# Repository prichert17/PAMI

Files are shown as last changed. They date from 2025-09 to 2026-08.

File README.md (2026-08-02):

# Projet PAMI (2025-2026) - Eurobot

Ce dépôt documente le projet PAMI (Petit Actionneur Motorisé Indépendant) sur lequel j'ai travaillé pendant un an, dans le cadre de la coupe Eurobot 2026. Il centralise l'ensemble de la conception matérielle (deux PCB, structure mécanique) et logicielle du robot. 

<p align="center">
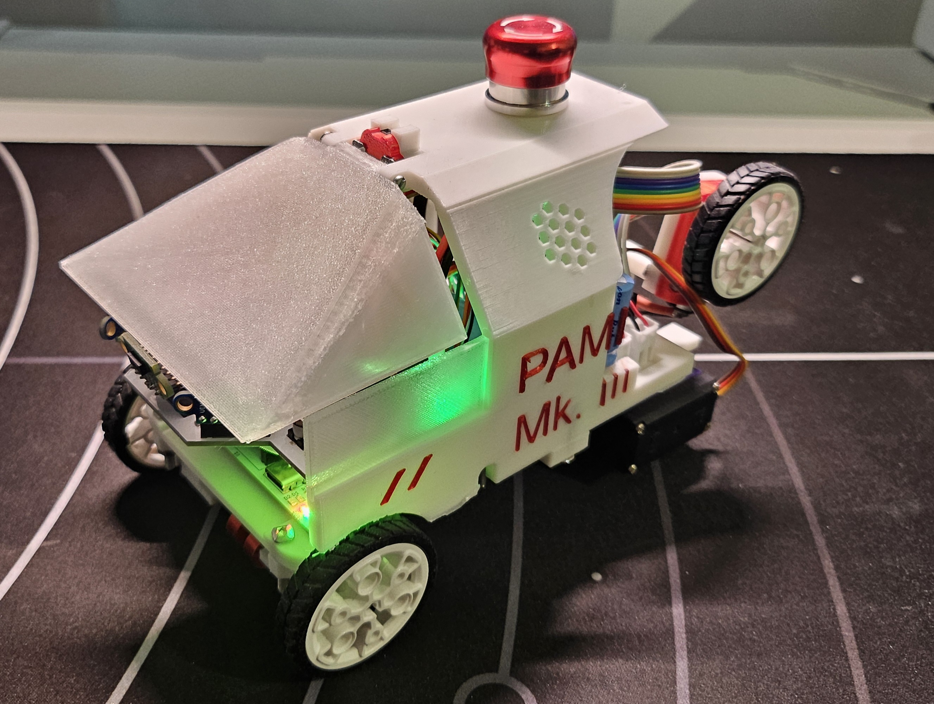
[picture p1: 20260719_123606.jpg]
  
  <br>
  <em>Légende : Photo du robot PAMI assemblé</em>
</p>

<p align="center">
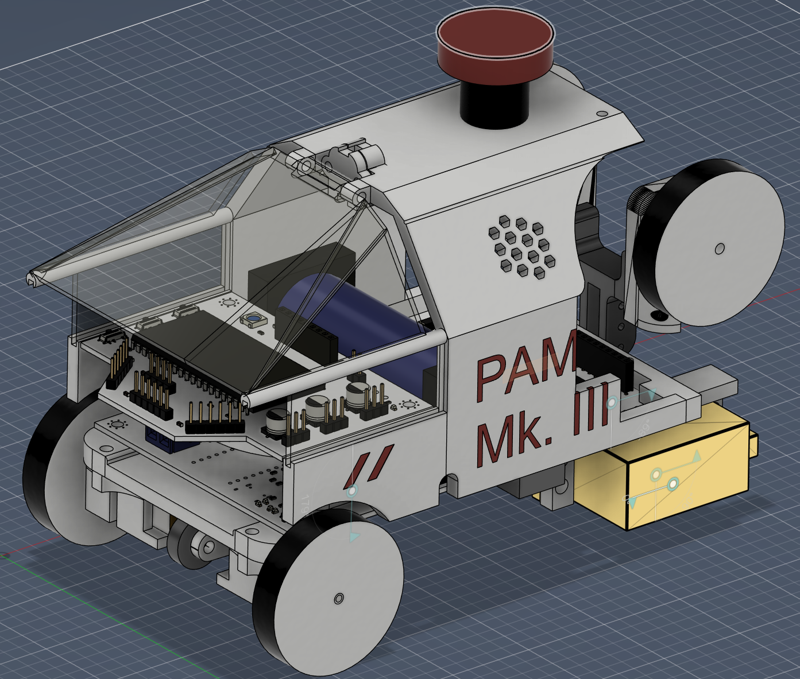
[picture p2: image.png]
  
  <br>
  <em>Légende : Rendu 3D du robot (Fusion 360)</em>
</p>

## Codes principaux

Pour mieux comprendre l'architecture du système, voici les trois éléments importants du dépôt :

*   **[`PAMI_2026/`](./Projects/PAMI_2026)** : Contient le code haut niveau qui est exécuté sur le microcontrôleur **ESP32**.
*   **[`Projects/Asservissement_G4/`](./Projects/Asservissement_G4)** : Contient tout le code de l'asservissement, de l'odométrie et le contrôle des moteurs. Ce code tourne sur la carte **NUCLEO-G431KB** (STM32).
*   **[`Projects/IHM_PAMI_2026.py`](./Projects/IHM_PAMI_2026.py)** : Une interface homme-machine (IHM) développée en Python qui permet de lire et visualiser en temps réel les coordonnées et l'état du PAMI lors des phases de tests.

---

## Architecture Bas Niveau : PCB Principal (Contrôle Moteurs & Alimentation)

Le robot dispose de deux cartes électroniques (PCB). La partie bas niveau, gérée par le PCB principal s'occupe de l'alimentation générale et de la motricité du robot. Le PAMI est assez compact : ses dimensions finales sont de 10.5cm par 19cm avec ses bras repliés (et 24cm bras dépliés), ce qui a imposé des contraintes sur le routage du circuit et le choix des composants.

### 1. Gestion de la Batterie et Alimentation
Le robot est alimenté par une unique cellule de batterie LiFePO4 au format 26650. Le circuit d'alimentation a subi plusieurs modifications suite à des problèmes rencontrés lors du développement :

*   **Le choix du LiFePO4 :** Bien que l'intégration de cette chimie ait rendu la conception du circuit d'alimentation plus complexe (notamment pour la régulation de tension, le prix plus élevé), c'est un choix qui reste très avantageux. Le LiFePO4 est extrêmement sécurisé (aucun risque d'incendie, pas besoin de sac ignifugé contrairement aux batteries LiPo), il offre un excellent courant de décharge (15A) pour les moteurs, et l'utilisation d'une seule et unique cellule simplifie grandement le processus de charge (pas d'équilibrage entre deux cellules nécessaire).
*   **Port USB C intégré :** Pour une simplicité d'usage maximale, un port USB C standard a été intégré au design, permettant de recharger facilement la batterie avec n'importe quel chargeur ou batterie externe.
*   **Circuit de Charge :** La charge est gérée directement sur le PCB par un composant dédié à ce type de batterie, le **CN3058E**, avec des LEDs indicatrices (Charge en cours / Charge terminée).
*   **Sécurité Batterie :** La batterie est surveillée par un IC de protection **HY2112**, associé à un double MOSFET N-Channel (FS8205A) pour couper le circuit en cas de problème.
*   **Régulation de tension :** La tension de la cellule LiFePO4 pouvant monter à 3.6V (ce qui est trop élevé pour l'ESP32 et certains capteurs), j'ai opté pour un convertisseur **Buck-Boost (TPS63000)** au lieu d'un simple circuit Boost. Il assure un 3.3V parfaitement stable en abaissant ou élevant la tension de la batterie selon les besoins, pour un courant jusqu'à 1A.
*   **Le problème des appels de courant :** Un problème est survenu avec l'alimentation des servomoteurs. Leurs appels de courant créaient d'énormes chutes de tension (la tension de la batterie chutait jusqu'à 2.4V pendant un court instant). Le robot ne parvenait pas à se lever de manière autonome, la tension de la batterie passait en dessous du seuil limite du circuit boost 6V. La cause : la résistance interne du boitier de la batterie 26650 et des pistes de cuivre trop fines (1.5mm) qui ne supportaient pas les pics d'intensité très élevés (pouvant monter jusqu'à 3A sur le rail 6V, soit quasiment 6A en sortie de la batterie). Le problème a été résolu en soudant un condensateur de 2200µF (10V) directement à l'entrée du boost 6V pour agir comme une réserve d'énergie, ce qui diminuait fortement la chute de tension.

### 2. Odométrie et Asservissement (NUCLEO-G431KB)
La carte intègre un microcontrôleur STM32 (NUCLEO-G431KB) programmé en C++ pour gérer la dynamique temps-réel du robot. Un travail conséquent a été réalisé sur la fiabilité des déplacements et la prévention du patinage.

*   **Odométrie Haute Fréquence (500Hz) :** La position exacte du robot (X, Y, Angle) est calculée 500 fois par seconde. Les encodeurs incrémentiels des roues renvoient des signaux en quadrature décodés de manière purement matérielle par les Timers du STM32. Le code gère les débordements de compteurs (overflow des timers 16 bits) pour assurer un suivi sans erreur.
*   **Asservissement PID en 2 Phases (100Hz) :** Le contrôle de la trajectoire s'effectue via une boucle PID (Proportionnel, Intégral, Dérivé) actualisée à 100Hz. Pour rejoindre une cible, l'algorithme utilise une logique en deux temps :
    1. **Rotation pure :** Le robot pivote sur lui-même pour s'aligner parfaitement vers sa cible.
    2. **Avance avec correction :** Une fois aligné, il avance en ligne droite tout en maintenant son angle de manière active. Si le robot doit dévier fortement, la commande linéaire est automatiquement réduite pour privilégier la rotation et garder un mouvement fluide.
*   **Traction Control & Anti-Patinage :** Les robots de la coupe Eurobot sont sujets au patinage (poussière, accélération forte), ce qui fausse instantanément l'odométrie. J'ai donc un algorithme de détection de glissement : si la différence de vitesse mesurée entre la roue gauche et droite devient anormalement élevée, le STM32 détecte la perte d'adhérence et réduit la commande PWM envoyée aux moteurs.
*   **Performances :** À pleine vitesse, les moteurs tournent à environ 5 tours/seconde, propulsant le PAMI à 68 cm/s (2.4 km/h). La dérive odométrique pure a été mesurée à environ 2cm d'erreur pour 1 mètre parcouru en ligne droite.
*   **Communication Inter-Cartes :** Le STM32 transmet continuellement ses données d'odométrie et son état au cerveau central (l'ESP32) via une liaison série (UART), dont le protocole est détaillé dans `pami_com.h`.

<p align="center">
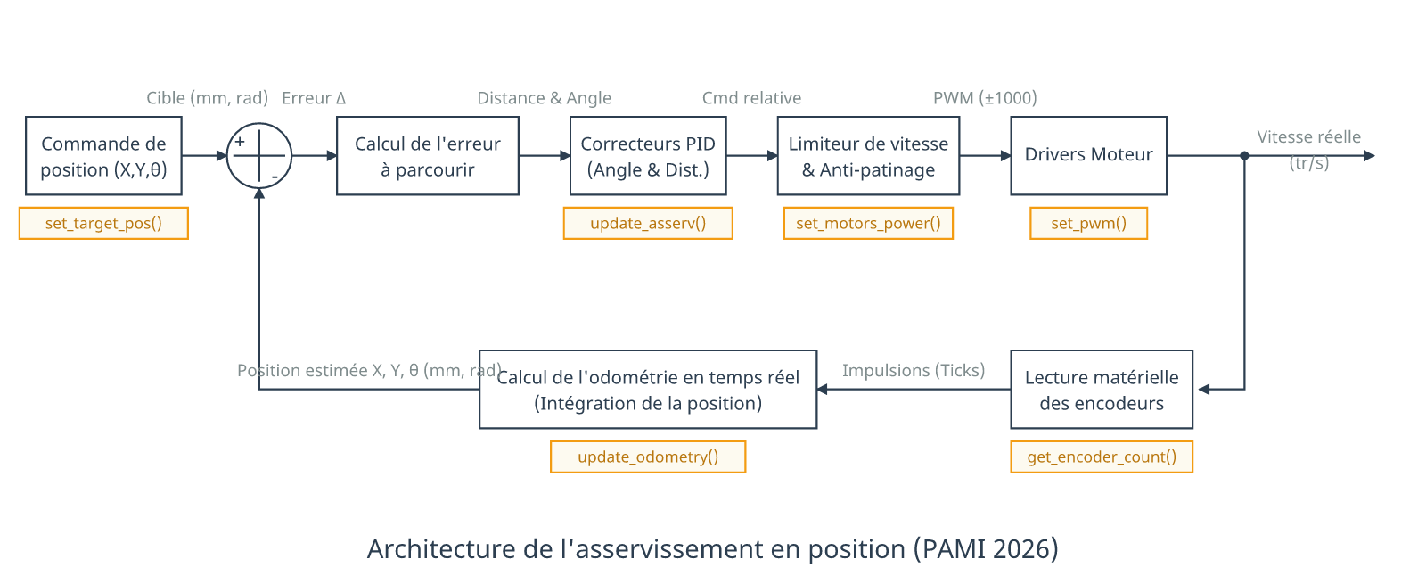
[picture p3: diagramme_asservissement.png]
  
  <br>
  <em>Légende : Schéma de l'architecture d'asservissement du STM32.</em>
</p>

### Schématique du PCB Principal

Voici la schématique électrique du PCB principal (Moteurs & Alimentation) montrant l'interconnexion entre la NUCLEO, les drivers moteurs, le circuit de charge de la batterie et le régulateur Buck-Boost :

<p align="center">
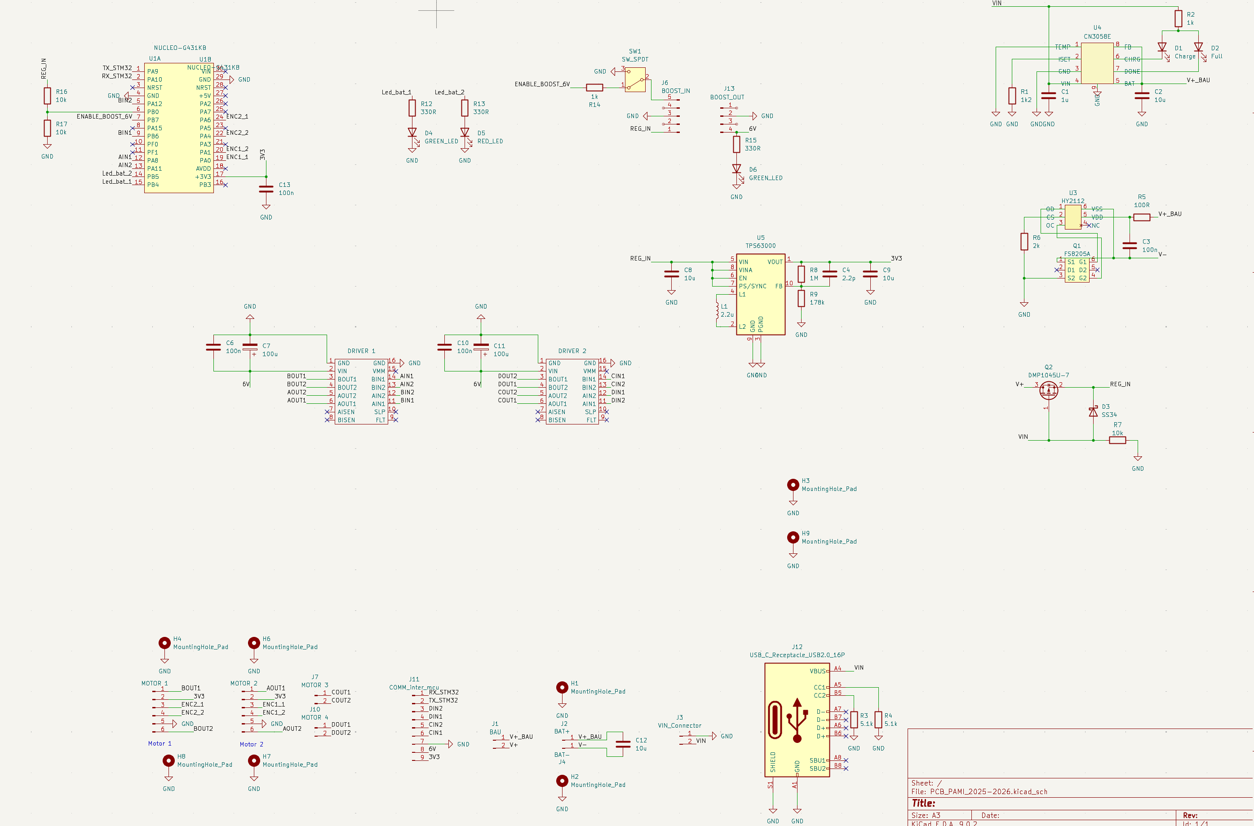
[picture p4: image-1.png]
  
  <br>
  <em>Légende : Schématique détaillée du PCB d'alimentation</em>
</p>

<p align="center">
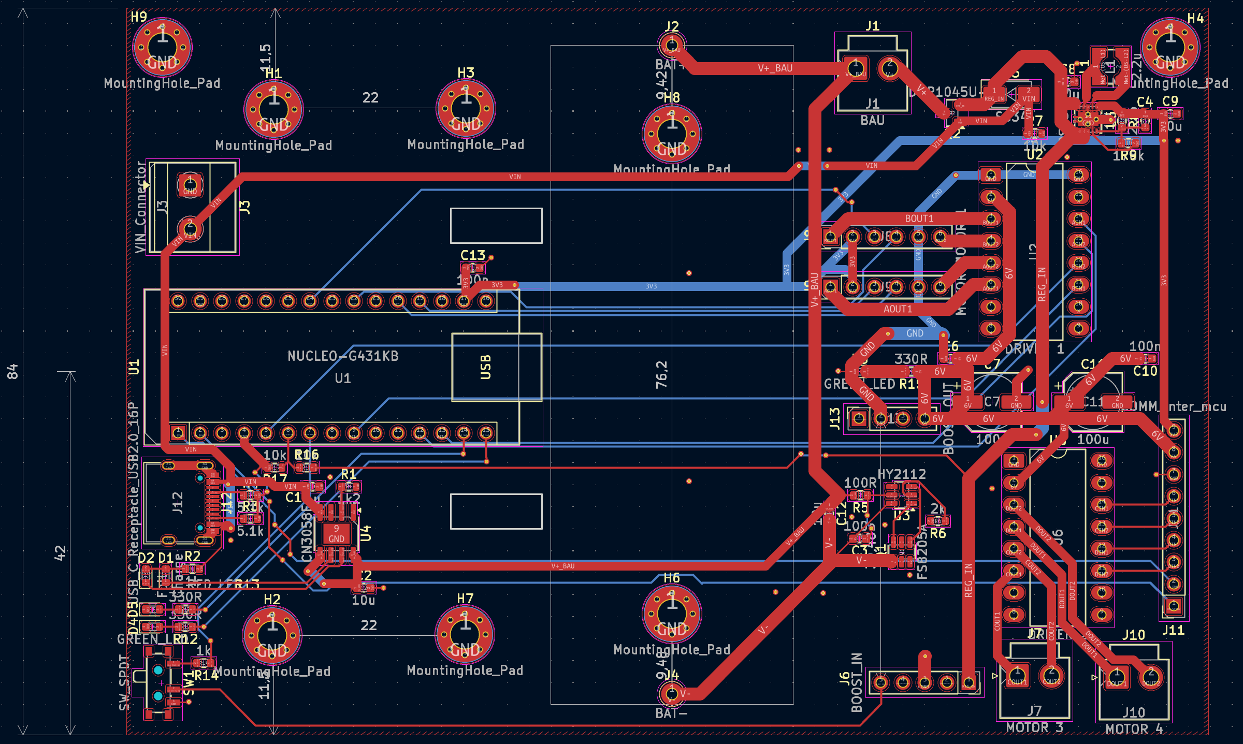
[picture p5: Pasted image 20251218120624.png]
  
  <br>
  <em>Légende : Routage du PCB d'alimentation</em>
</p>

## Architecture Haut Niveau : Capteurs et Stratégie (ESP32)

La seconde carte du robot embarque un **ESP32**. Ce microcontrôleur fait office de cerveau principal : il ne gère pas les moteurs principaux directement, mais s'occupe de la prise de décision, de la vision spatiale (capteurs ToF matriciels), de la gestion du temps de match et de l'interface utilisateur.

### 1. Multitâche avec FreeRTOS
Pour garantir une réactivité maximale sans bloquer le système lors de la lecture des capteurs I2C (qui peut être lente), le code de l'ESP32 est architecturé autour du système d'exploitation temps réel **FreeRTOS**. Les tâches sont réparties sur les deux cœurs (Cores) physiques du processeur :

*   **Core 1 (Haute Priorité) :** 
    *   `Task_Comms` : Écoute en continu le port série UART pour ne rater aucune mise à jour de position venant du STM32. Permet aussi le debug lorsque branché à un PC.
    *   `Task_Strategy` : La machine à états principale du robot. Elle dicte les déplacements et gère le chronomètre du match.
*   **Core 0 (Basse Priorité) :**
    *   `Task_Tofs` : Gère le multiplexage et l'acquisition des données des 3 capteurs de distance matriciels sur le bus I2C.
    *   `Task_IHM` : Contrôle les animations de la LED d'état WS2812B et pilote les servomoteurs d'actionnement de fin de match.

### 2. Vision Spatiale : Capteurs ToF (VL53L5CX) et Anti-Collision
Le robot est équipé de 3 capteurs Time-of-Flight matriciels **VL53L5CX** (Centre, Gauche, Droite) configurés en résolution 8x8 zones à 15 Hz.

*  L'ESP32 configure dynamiquement les adresses I2C des 3 capteurs au démarrage (vers `0x30`, `0x31`, `0x32`) en utilisant les broches `XSHUT` (LPN), ce qui permet de tous les utiliser sur le même bus I2C à 400kHz.
*   **Calcul de repère absolu :** Lorsqu'un capteur détecte un obstacle, la tâche ne se contente pas de renvoyer une distance. Elle utilise la position instantanée du robot (X, Y, θ) et la géométrie des capteurs (FOV de 45°/60°, offset physique en X/Y) pour projeter l'obstacle sur le système de coordonnées du terrain. Le robot sait exactement où se trouve l'obstacle sur la table.
*   **Évitement d'urgence :** Si un objet est détecté à moins de 10 cm dans les zones critiques, le STM32 reçoit instantanément un ordre d'arrêt (`stopMotors()`) via l'UART. Le robot se met en pause et reprend sa route de lui-même dès que l'obstacle disparaît.

### 3. Stratégie et Machine à États
La logique de match est dictée par une machine à états :

1.  **`STATE_WAIT` (Attente) :** L'ESP32 lit la couleur de l'équipe via un switch (`PIN_SW_COLOR`). L'ensemble du système de coordonnées (points de départ, waypoints, cibles) est automatiquement symétrisée (inversion de l'axe X) si le robot est dans l'équipe bleue. Le robot attend le retrait de la tirette, en affichant la couleur du terrain sur la led d'IHM.
2.  **`STATE_DELAY` (Attente 85s) :** Selon les règles, les PAMI ne peuvent entrer en action qu'à la fin du match principal. Au retrait de la tirette, le robot reset son odométrie (`resetSTM32`) puis attend pendant 85 secondes.
3.  **`STATE_GAME` (Match) :** L'ESP32 commence à lire sa route de Waypoints et envoie les coordonnées cibles au STM32. Si un obstacle fixe est détecté lors du premier déplacement, un waypoint bonus est généré dynamiquement pour modifier la stratégie en cours de match.
4.  **`STATE_END` (Fin de match) :** À T+99s, le robot stoppe ses moteurs et déploie ses bras à l'aide de ses servomoteurs.

### 4. Communication Inter-Cartes et IHM
*   **Protocole UART :** L'ESP32 et le STM32 communiquent à 115200 bauds. Le STM32 "stream" en continu ses coordonnées au format `X:123,Y:456,Z:1.57`, que l'ESP32 parse via la fonction `parseSTM32Data`. En retour, l'ESP32 envoie des commandes simples au STM32 (`mode auto`, `stop`, `X:1000`, `reset:x:y:z`).
*   **Feedback Visuel (LED WS2812B) :** Sans écran, le debug visuel repose principalement sur la LED RGB adressable intelligente. Sa couleur et son rythme de clignotement indiquent instantanément l'état du système : 
    *   *Rouge fixe* : Batterie LiFePO4 faible.
    *   *Orange clignotant* : Obstacle détecté par ToF.
    *   *Vert clignotant* : Tirette retirée, en cours d'attente (85s).
    *   *Vert fixe* : Match en cours.
    *   *Jaune/Bleu* : Robot en attente de la tirette, affiche la couleur de l'équipe sélectionnée.

### 5. Conception de la Carte ESP32 (PCB Haut Niveau)
Pour centraliser toutes ces fonctionnalités, un second PCB a été conçu spécifiquement pour accueillir l'ESP32. Cette carte vient se superposer à la carte d'alimentation principale et gère toute la logique périphérique :

*   **L'Interface Utilisateur (Switchs et LED) :** La carte intègre directement 3 interrupteurs (`DEBUG` pour l'affichage des logs, `TERRAIN` pour le choix de la couleur, et `MODE` pour basculer entre le mode automatique et le contrôle manuel via manette bluetooth), le connecteur pour la `Tirette` de démarrage, ainsi que la LED d'état WS2812B.
*   **Les Capteurs ToF :** Le routage contient aussi les 3 capteurs VL53L5CX (avec les angles adéquats pour couvrir l'avant du robot). On y retrouve le bus I2C commun (SDA/SCL) ainsi que les broches dédiées `LPN1`, `LPN2`, et `LPN3` permettant d'allumer les capteurs séquentiellement pour modifier leur adresse I2C au boot.
*   **Les Actionneurs (Servomoteurs) :** 3 connecteurs pour servomoteurs (`SERVO m1`, `SERVO m2`, `SERVO m3`) sont présents. Ils sont alimentés directement par le rail **6V** provenant de la carte principale, et commandés par des broches PWM de l'ESP32. Des condensateurs de 100µF sont placés au plus près des connecteurs pour lisser les appels de courant.
*   **Interconnexion :** Le connecteur `COMM_inter_mcu` assure la liaison avec la carte STM32 pour l'UART (TX/RX), les alimentations (3.3V et 6V), et les deux moteurs auxiliaires posés sur l'actionneur du robot qui lui permette de gravire des obstacles.

Voici la schématique et le routage de cette seconde carte :

<p align="center">
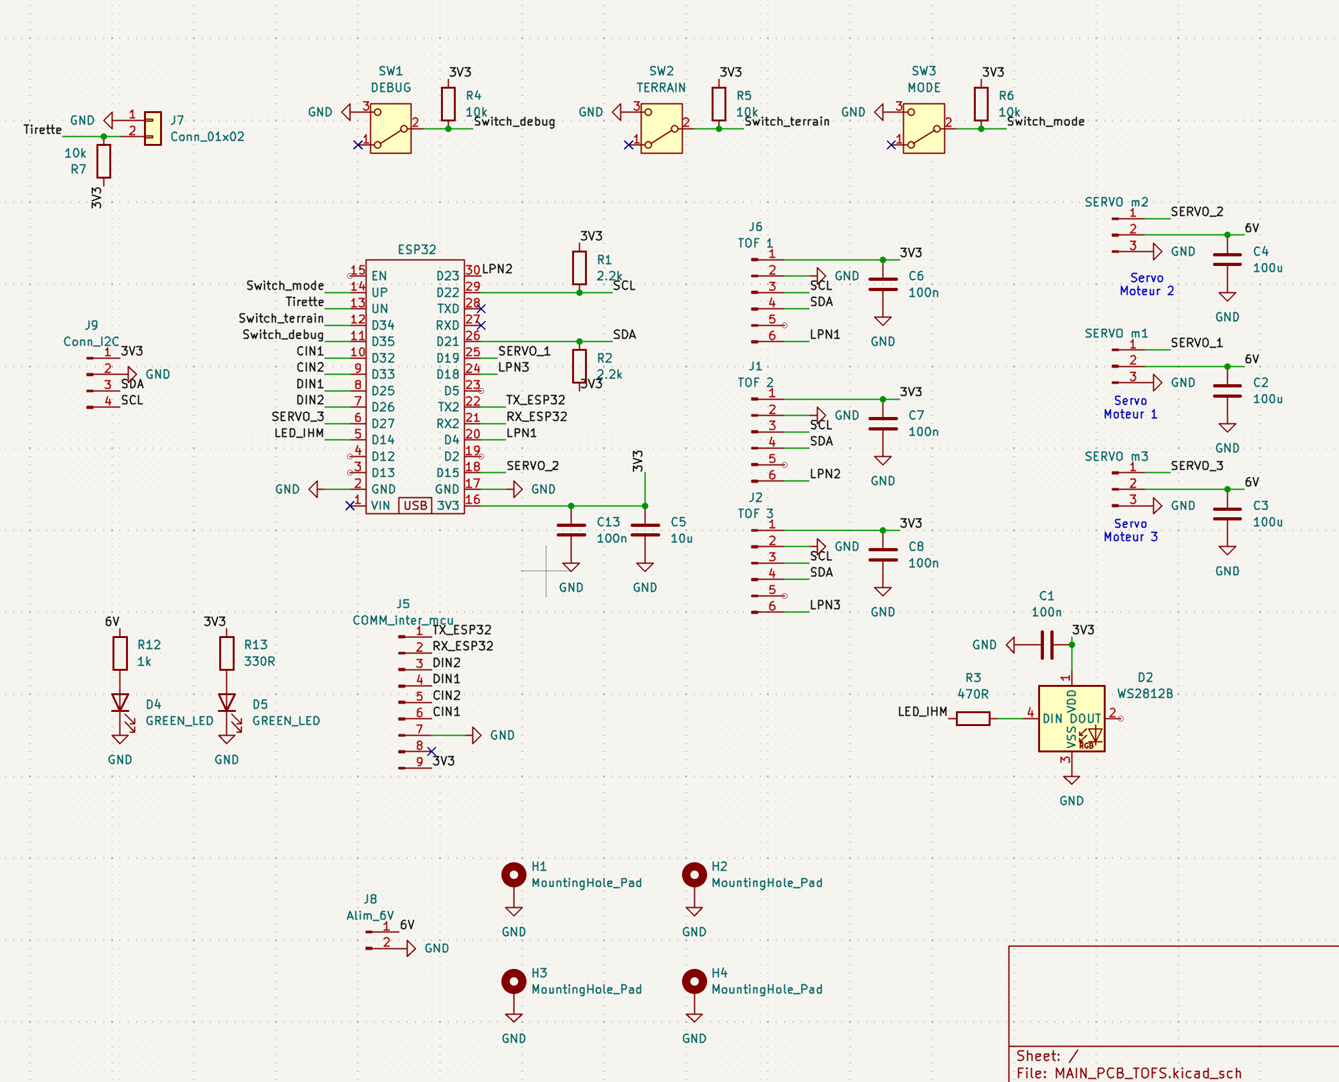
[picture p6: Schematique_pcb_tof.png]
  
  <br>
  <em>Légende : Schématique détaillée du PCB ESP32 (Capteurs, IHM, Servos)</em>
</p>

<p align="center">
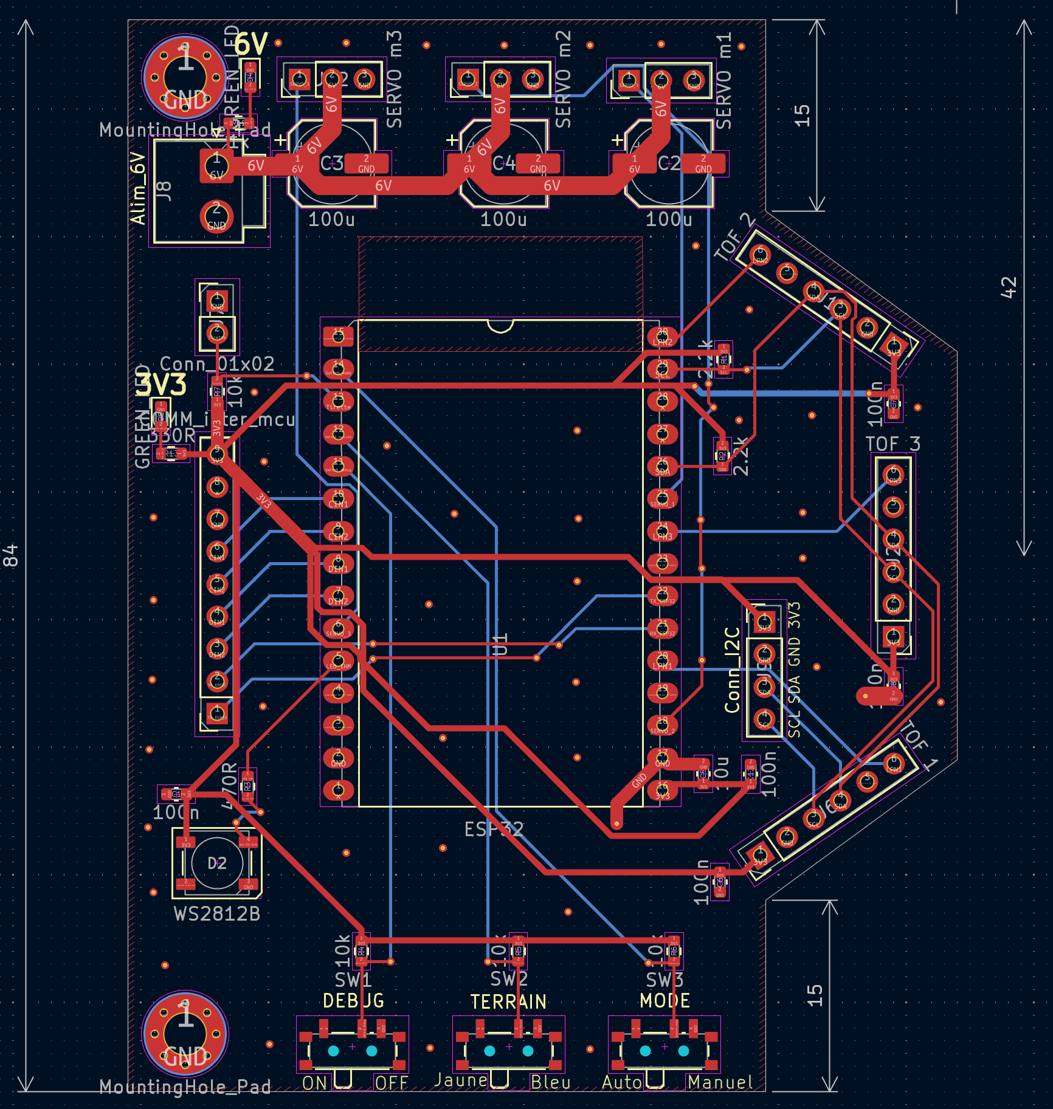
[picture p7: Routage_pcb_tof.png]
  
  <br>
  <em>Légende : Routage du PCB ESP32</em>
</p>

---

## Conclusion et Démonstration en Match

Après de nombreuses itérations matérielles (sur les deux itérations de PCB et la mécanique) ainsi qu'un gros travail d'optimisation logicielle, le PAMI a su remplir son rôle de manière fiable et concluante.

Voici une courte vidéo démontrant son fonctionnement lors d'un match (cas le plus simple, sans obstacles) :

https://github.com/user-attachments/assets/42d38b15-34ad-48e5-a77b-8a1eeed6a4e9

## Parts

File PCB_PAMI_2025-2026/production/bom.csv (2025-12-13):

Designator | Footprint | Quantity | Value | LCSC Part #
C1 | 0603 | 1 | 1u
C10, C13, C3, C6 | 0603 | 4 | 100n
C11, C7 | CP_Elec_6.3x5.4 | 2 | 100u
C12, C2, C8, C9 | 0603 | 4 | 10u
C4 | 0603 | 1 | 2.2p
D1 | 0603 | 1 | Charge
D2 | 0603 | 1 | Full
D3 | D_SMA | 1 | SS34
D4, D6 | 0603 | 2 | GREEN_LED
D5 | 0603 | 1 | RED_LED
J1 | JST_VH_B2P-VH_1x02_P3.96mm_Vertical | 1 | BAU
J10 | JST_VH_B2P-VH_1x02_P3.96mm_Vertical | 1 | MOTOR 4
J11 | PinSocket_1x09_P2.54mm_Vertical | 1 | COMM_inter_mcu
J12 | USB_C_Receptacle_HRO_TYPE-C-31-M-12 | 1 | USB_C_Receptacle_USB2.0_16P
J13 | PinSocket_1x04_P2.54mm_Vertical | 1 | BOOST_OUT
J2 | TestPoint_THTPad_D2.5mm_Drill1.2mm | 1 | BAT+
J3 | TerminalBlock_Phoenix_MKDS-1,5-2-5.08_1x02_P5.08mm_Horizontal | 1 | VIN_Connector
J4 | TestPoint_THTPad_D2.5mm_Drill1.2mm | 1 | BAT-
J6 | PinSocket_1x05_P2.54mm_Vertical | 1 | BOOST_IN
J7 | JST_VH_B2P-VH_1x02_P3.96mm_Vertical | 1 | MOTOR 3
J8 | PinHeader_1x06_P2.54mm_Vertical | 1 | MOTOR 1
J9 | PinHeader_1x06_P2.54mm_Vertical | 1 | MOTOR 2
L1 | L_Wuerth_WE-TPC-3816 | 1 | 2.2u
Q1 | SOT-23-6 | 1 | FS8205A
Q2 | SOT-23 | 1 | DMP1045U-7
R1 | 0603 | 1 | 1k2
R12, R13, R15 | 0603 | 3 | 330R
R14, R2 | 0603 | 2 | 1k
R16, R17, R7 | 0603 | 3 | 10k
R3, R4 | 0603 | 2 | 5.1k
R5 | 0603 | 1 | 100R
R6 | 0603 | 1 | 2k
R8 | 0603 | 1 | 1M
R9 | 0603 | 1 | 178k
SW1 | SW_SPDT_PCM12 | 1 | SW_SPDT
U1 | Arduino_Nano | 1 | NUCLEO-G431KB
U2 | DIP-16_W10.16mm_LongPads | 1 | DRIVER 1
U3 | SOT-23-6 | 1 | HY2112
U4 | SOIC-8-1EP_3.9x4.9mm_P1.27mm_EP2.29x3mm | 1 | CN3058E
U5 | Texas_DRC0010J_ThermalVias | 1 | TPS63000
U6 | DIP-16_W10.16mm_LongPads | 1 | DRIVER 2

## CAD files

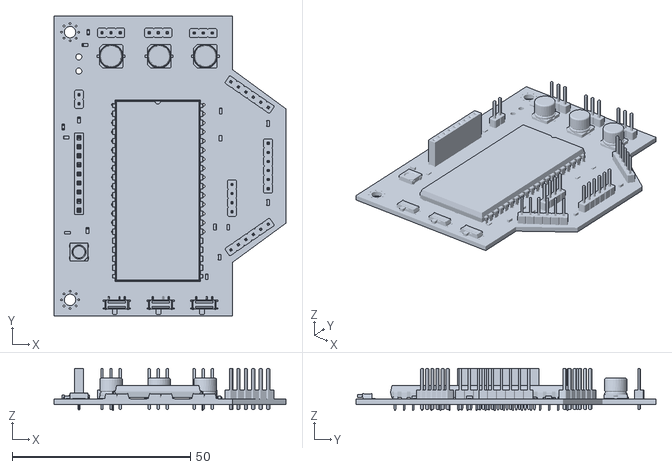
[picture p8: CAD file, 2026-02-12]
MAIN_PCB_TOFS/MAIN_PCB_TOFS.stl
65.0 x 84.0 x 11.8

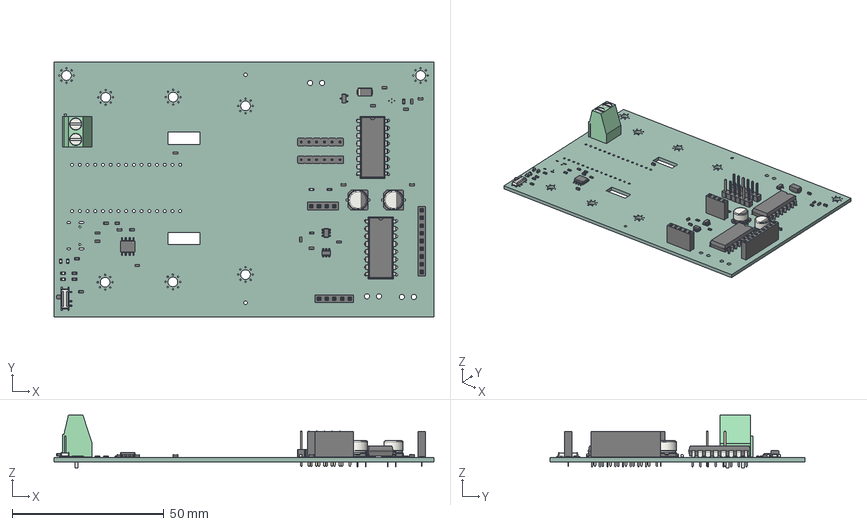
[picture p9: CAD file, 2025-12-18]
PCB_PAMI_2025-2026/PCB_PAMI_2025-2026.step
125.0 x 84.0 x 17.3 mm
CP_Elec_6.3x5.4 x 2
C_0603_1608Metric x 10
R_0603_1608Metric x 15
SOT-23-6 x 2
SOT-23
LED_0603_1608Metric x 5
PinSocket_1x04_P2.54mm_Vertical
D_SMA
DIP-16_W10.16mm x 2
PinHeader_1x06_P2.54mm_Vertical x 2
PinSocket_1x05_P2.54mm_Vertical
SOIC-8-1EP_3.9x4.9mm_P1.27mm_EP2.29x3mm
TerminalBlock_Phoenix_MKDS-1,5-2-5.08_1x02_P5.08mm_Horizontal
PinSocket_1x09_P2.54mm_Vertical
SW_SPDT_PCM12
PCB_PAMI_2025-2026_PCB

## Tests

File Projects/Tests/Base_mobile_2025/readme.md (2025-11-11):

# Base mobile

- [Base mobile](#base-mobile)
  - [Principe de fonctionnement](#principe-de-fonctionnement)
    - [Moteurs \& encodeurs](#moteurs--encodeurs)
    - [Drivers](#drivers)
  - [Odométrie \& commande](#odométrie--commande)
    - [Odométrie](#odométrie)
    - [Commande](#commande)
  - [Commande CAN](#commande-can)

## Principe de fonctionnement 
La base mobile est une base holonome à trois roues, capable de translater dans toutes les directions sans changer d'orientation. Elle est asservie en vitesse et en position.

### Moteurs & encodeurs
Les moteurs sont des moteurs à courant continu 12V [Pololu 4751](https://www.pololu.com/product/4751) équipé d'encodeur 64 CPR et d'un motoréducteur 18,75:1. On dispose donc de 1200 pas d'encodeurs par révolution de l'arbre de sortie, ce qui permet de mesurer la position relative de l'arbre moteur et d'en dériver la vitesse de rotation de la roue.

### Drivers
Les drivers moteurs permettent de contrôler la vitesse et le sens de rotation des moteurs. Il sont basé sur le circuit intégré [DRV8256P](https://www.pololu.com/product/4039), choit pour leur linéarité. Ils sont alimentés par une source de tension continue de 12V capable de délivrer plusieurs Ampères. La vitesse du moteur est contrôlée par le rapport cyclique d'un signal PWM généré par le microcontrôleur. La direction est contrôlée par l'état d'un autre signal généré par le microcontrôleur.  

## Odométrie & commande
Afin de pouvoir correctement contrôler la vitesse et la position de la base mobile, il est primordial de connaître sa position et sa vitesse. C'est le rôle de l'odométrie.

### Odométrie
Le déplacement de la base mobile peut être calculer à partir de la rotation des roues. Une loi peut être établie entre la rotation des trois roues $s_1$, $s_2$ et $s_3$ et le déplacement en $x$, $y$ et la rotation $\theta$.
On peut établire une relation entre la vitesse des roues et la vitesse de la base mobile dans son référentiel selon 
$\begin{pmatrix}x\cr y\cr \theta\cr\end{pmatrix}=\begin{bmatrix}A_{11} &A_{12} & A_{13}\\A_{21} & A_{22} & A_{23}\\A_{31} & A_{32} & A_{33} \end{bmatrix}\times\begin{pmatrix}s_1\cr s_2\cr s_3\cr\end{pmatrix}$. Les coefficients $A_{ij}$ sont dépendant de la géométrie de la base mobile. Plus d'information sont disponible dans [cet article](https://www.researchgate.net/publication/348123505_Holonomic_Implementation_of_Three_Wheels_Omnidirectional_Mobile_Robot_using_DC_Motors) et [cet article](https://www.researchgate.net/publication/309002190_Design_Implementation_and_Validation_of_the_Three-Wheel_Holonomic_Motion_System_of_the_Assistant_Personal_Robot_AP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).

### Commande
Le calcul de la commande consiste à determiner à quelle vitesse doivent tourner les roues pour faire avancer la  base mobile dans la direction voulue. On peut calculer le vecteur $\begin{pmatrix}s_1\cr s_2\cr s_3\cr\end{pmatrix}$ en utilisant l'inverse de la matrice citée précédement pour l'obtenir à partir de $\begin{pmatrix}x\cr y\cr \theta\cr\end{pmatrix}$.

## Commande CAN
Les commandes CAN sont listée ici:

*En construction*

| id | action | parameters | response |
|----|---|---|---|
|0| ... | | |
|1| ... | | |
|2| ... | | |
|3| ... | | |

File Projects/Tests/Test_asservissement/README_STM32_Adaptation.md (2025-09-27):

# Adaptation du code pour STM32 L432KC

## Changements effectués

### 1. Configuration PlatformIO (platformio.ini)
- **Avant** : `platform = espressif32`, `board = esp32dev`
- **Après** : `platform = ststm32`, `board = nucleo_l432kc`
- Framework Arduino maintenu pour compatibilité

### 2. Pins utilisées (adaptées au STM32 L432KC)
| Fonction | ESP32 Original | STM32 L432KC | Commentaire |
|---|---|---|---|
| Moteur gauche PWM 1 | 25 | PA8 | TIM1_CH1 |
| Moteur gauche PWM 2 | 26 | PA9 | TIM1_CH2 |
| Moteur droit PWM 1 | 32 | PA10 | TIM1_CH3 |
| Moteur droit PWM 2 | 33 | PA11 | TIM1_CH4 |
| Encodeur gauche A | 27 | PA0 | GPIO avec interrupt |
| Encodeur gauche B | 14 | PA1 | GPIO avec interrupt |
| Encodeur droit A | 35 | PA6 | GPIO avec interrupt |
| Encodeur droit B | 34 | PA7 | GPIO avec interrupt |
| UART TX | - | PA2 | USART2 → Serial2 |
| UART RX | - | PA3 | USART2 → Serial2 |

### 3. Modifications majeures

#### **Encodeurs en quadrature (X4)**
- **Avant** : Interruptions simples sur un seul signal par encodeur
- **Après** : Décodage quadrature complet X4 avec interruptions sur A et B
- **Avantage** : 4x plus de résolution, détection de sens automatique
- **Logique** : Table de décodage quadrature dans ISR `enc1_ISR()` et `enc2_ISR()`

#### **Contrôle PID par timer matériel**  
- **Avant** : Loop principale avec `millis()` 
- **Après** : ISR timer matériel `ctrlISR()` à 1kHz (TIM6)
- **Avantage** : Précision temporelle parfaite, CPU libéré

#### **PWM moteurs**
- **Signature conservée** : `set_vitesse(float cmd1, float cmd2)` identique
- **Pins** : Regroupées sur TIM1 (PA8..PA11) pour cohérence  
- **Fréquence** : Prêt pour 20kHz (actuellement fréquence par défaut Arduino)

#### **Communication UART**
- **Ajout** : `Serial2` sur PA2/PA3 pour communication ESP32
- **Format** : CSV `speed1,speed2,X,Y,theta` toutes les 500ms
- **Debug** : `Serial` USB maintenu

### 4. Fonctionnalités conservées
- ✅ Contrôle PWM sign-magnitude des moteurs (fonction `set_vitesse` inchangée)
- ✅ Régulation PID vitesse (mêmes paramètres kp, ki, kd)
- ✅ Calcul de position (odométrie) 
- ✅ Communication série (ajout UART vers ESP32)
- ✅ Variables robot (robotX, robotY, robotTheta) 

### 5. Améliorations apportées
- **Résolution encodeurs** : X4 vs simple comptage
- **Précision temporelle** : Timer matériel vs polling
- **Robustesse** : Décodage quadrature avec table d'états
- **Performance** : ISR dédiées, sections critiques optimisées
- **Communication** : Dual Serial (USB debug + UART vers ESP32)

## Tests d'acceptation réalisés
1. ✅ **Compilation** : Code compile sans erreur pour `nucleo_l432kc`
2. ✅ **Signature** : `set_vitesse(cmd1, cmd2)` inchangée
3. ✅ **Encodeurs** : Décodage quadrature X4 implémenté  
4. ✅ **PID** : Logique et paramètres conservés
5. ✅ **Timer** : ISR 1kHz pour contrôle précis

## Utilisation

### Compilation
```bash
platformio run
```

### Upload  
```bash
platformio run --target upload
```

### Monitoring
```bash 
platformio device monitor --baud 115200
```

### Communication ESP32
- **Port** : USART2 (PA2/PA3) à 115200 baud
- **Format** : `speed1,speed2,X,Y,theta\n`
- **Fréquence** : 2Hz (toutes les 500ms)

## Notes techniques

### Pinout NUCLEO-L432KC
- **PA8-PA11** : TIM1 CH1-4 (PWM moteurs)
- **PA0-PA1** : GPIO interrupt (encodeur gauche)  
- **PA6-PA7** : GPIO interrupt (encodeur droit)
- **PA2-PA3** : USART2 TX/RX (vers ESP32)
- **TIM6** : Timer contrôle PID

### Fréquences
- **PID** : 1 kHz (1ms précis)
- **Debug/UART** : 2 Hz (500ms)
- **PWM** : ~1 kHz (extensible 20 kHz)

### Résolution encodeurs
- **Avant** : 1400 CPR simple
- **Après** : 1400 × 4 = 5600 CPR (quadrature X4)

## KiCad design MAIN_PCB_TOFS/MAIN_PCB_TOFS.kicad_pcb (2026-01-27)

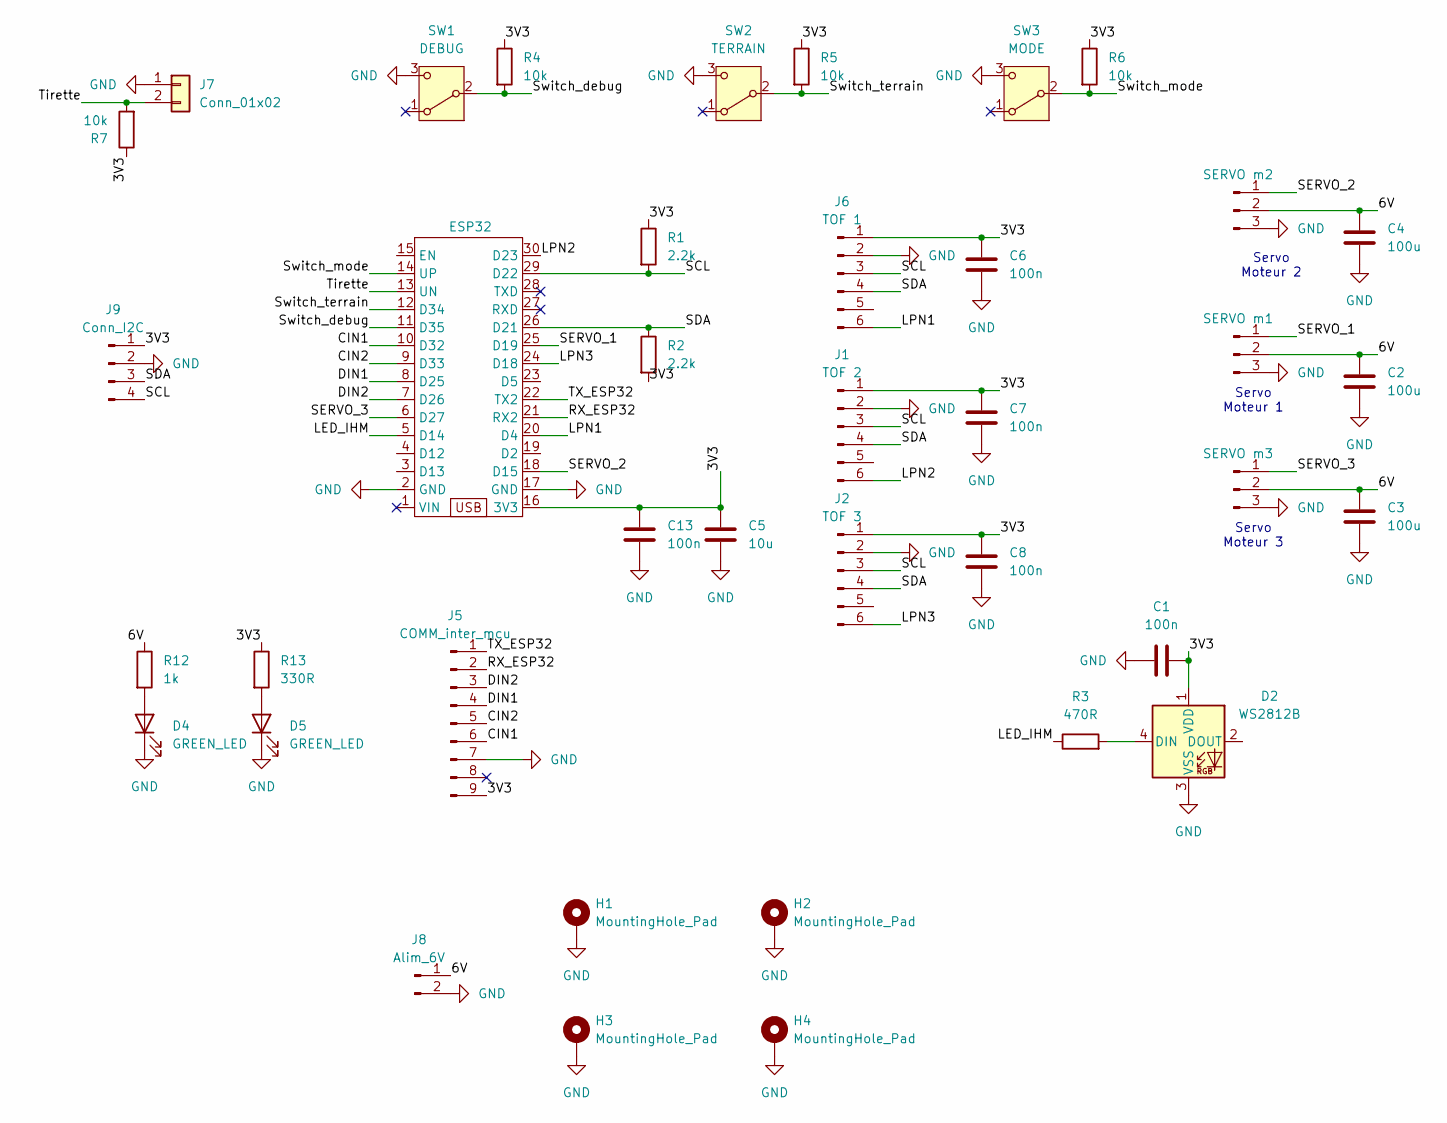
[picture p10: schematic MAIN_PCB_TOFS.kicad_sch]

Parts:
C1, C6, C7, C8, C13: 100n; C_0603_1608Metric
C2, C3, C4: 100u; CP_Elec_6.3x5.8
C5: 10u; C_0603_1608Metric
D2: WS2812B; LED_WS2812B_PLCC4_5.0x5.0mm_P3.2mm
D4, D5: GREEN_LED; LED_0603_1608Metric
H1, H2, H3, H4: MountingHole_Pad; MountingHole_3.2mm_M3_Pad_Via
J1: TOF 2; PinHeader_1x06_P2.54mm_Vertical
J2: TOF 3; PinHeader_1x06_P2.54mm_Vertical
J3: SERVO m2; PinHeader_1x03_P2.54mm_Vertical
J4: SERVO m1; PinHeader_1x03_P2.54mm_Vertical
J5: COMM_inter_mcu; PinSocket_1x09_P2.54mm_Vertical
J6: TOF 1; PinHeader_1x06_P2.54mm_Vertical
J7: Conn_01x02; PinHeader_1x02_P2.54mm_Vertical
J8: Alim_6V; JST_VH_B2P-VH_1x02_P3.96mm_Vertical
J9: Conn_I2C; PinHeader_1x04_P2.54mm_Vertical
J12: SERVO m3; PinHeader_1x03_P2.54mm_Vertical
R1, R2: 2.2k; R_0603_1608Metric
R3: 470R; R_0603_1608Metric
R4, R5, R6, R7: 10k; R_0603_1608Metric
R12: 1k; R_0603_1608Metric
R13: 330R; R_0603_1608Metric
SW1: DEBUG; SW_SPDT_PCM12
SW2: TERRAIN; SW_SPDT_PCM12
SW3: MODE; SW_SPDT_PCM12
U1: ESP32; DIP-30_W25.4mm_LongPads_esp32

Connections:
/3V3: C1.2, C5.1, C6.1, C7.1, C8.1, C13.1, D2.1 (VDD), J1.1, J2.1, J5.9, J6.1, J9.1, R1.1, R2.2, R4.1, R5.1, R6.1, R7.1, R13.1, U1.16 (3V3)
/6V: C2.1, C3.1, C4.1, J3.2, J4.2, J8.1, J12.2, R12.1
/CIN1: J5.6, U1.10 (D32)
/CIN2: J5.5, U1.9 (D33)
/DIN1: J5.4, U1.8 (D25)
/DIN2: J5.3, U1.7 (D26)
/LED_IHM: R3.1, U1.5 (D14)
/LPN1: J6.6, U1.20 (D4)
/LPN2: J1.6, U1.30 (D23)
/LPN3: J2.6, U1.24 (D18)
/RX_ESP32: J5.2, U1.21 (RX2)
/SCL: J1.3, J2.3, J6.3, J9.4, R1.2, U1.29 (D22)
/SDA: J1.4, J2.4, J6.4, J9.3, R2.1, U1.26 (D21)
/SERVO_1: J4.1, U1.25 (D19)
/SERVO_2: J3.1, U1.18 (D15)
/SERVO_3: J12.1, U1.6 (D27)
/Switch_debug: R4.2, SW1.2 (B), U1.11 (D35)
/Switch_mode: R6.2, SW3.2 (B), U1.14 (UP)
/Switch_terrain: R5.2, SW2.2 (B), U1.12 (D34)
/TX_ESP32: J5.1, U1.22 (TX2)
/Tirette: J7.2, R7.2, U1.13 (UN)
GND: C1.1, C2.2, C3.2, C4.2, C5.2, C6.2, C7.2, C8.2, C13.2, D2.3 (VSS), D4.1 (K), D5.1 (K), H1.1, H2.1, H3.1, H4.1, J1.2, J2.2, J3.3, J4.3, J5.7, J6.2, J7.1, J8.2, J9.2, J12.3, SW1.3 (C), SW2.3 (C), SW3.3 (C), U1.2 (GND), U1.17 (GND)
unnamed: D2.4 (DIN), R3.2
unnamed: D4.2 (A), R12.2
unnamed: D5.2 (A), R13.2

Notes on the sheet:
Servo Moteur 2
Servo Moteur 1
Servo Moteur 3

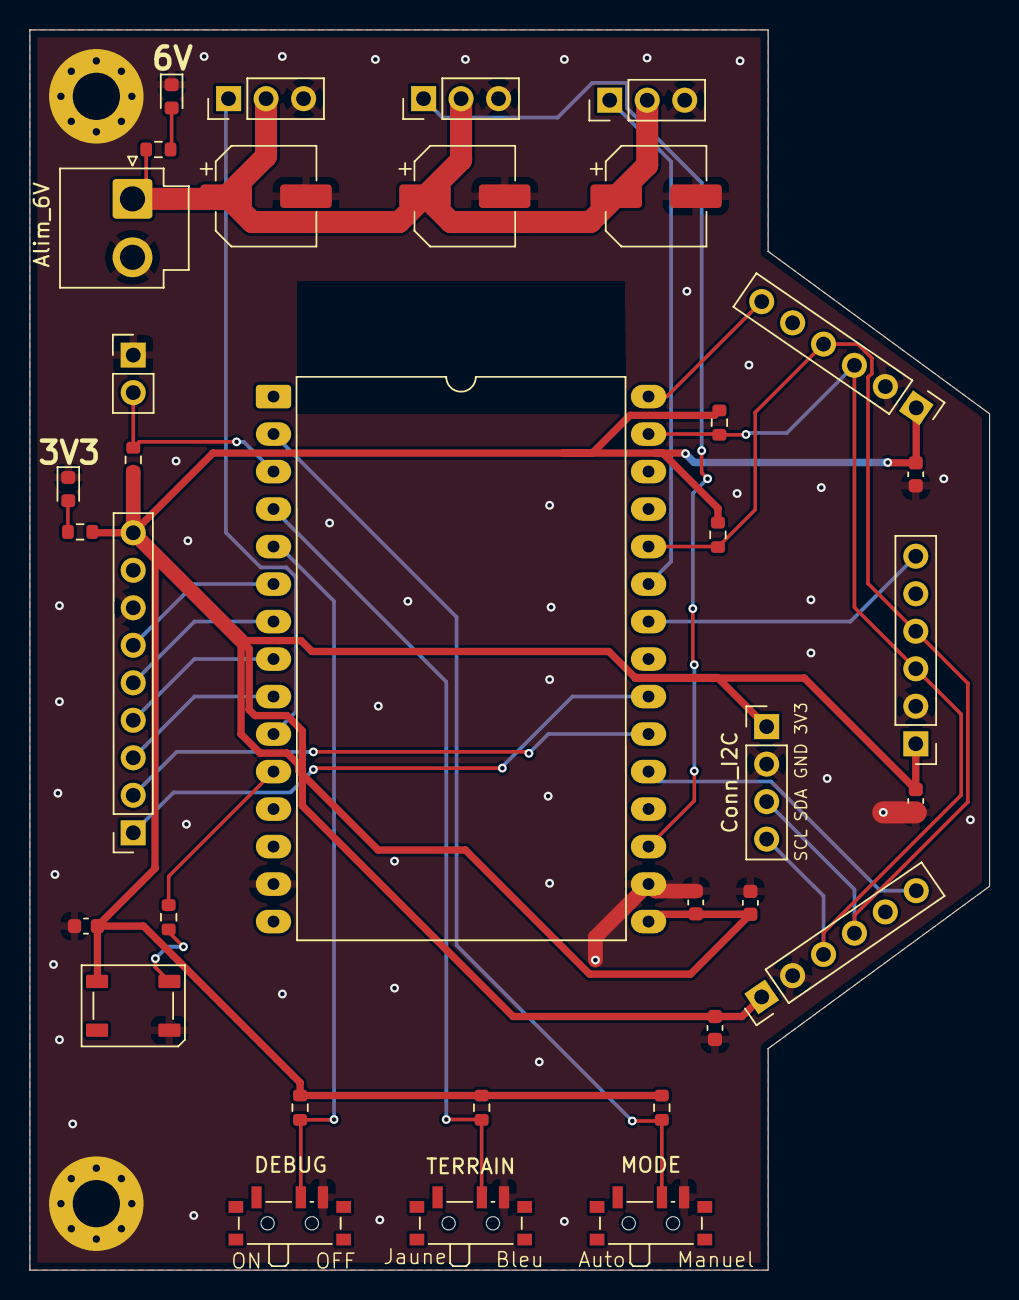
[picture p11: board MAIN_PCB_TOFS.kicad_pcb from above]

Board: 2 copper layers, 65.0 x 84.0 mm, 37 parts (0 on the bottom side), 25 nets.

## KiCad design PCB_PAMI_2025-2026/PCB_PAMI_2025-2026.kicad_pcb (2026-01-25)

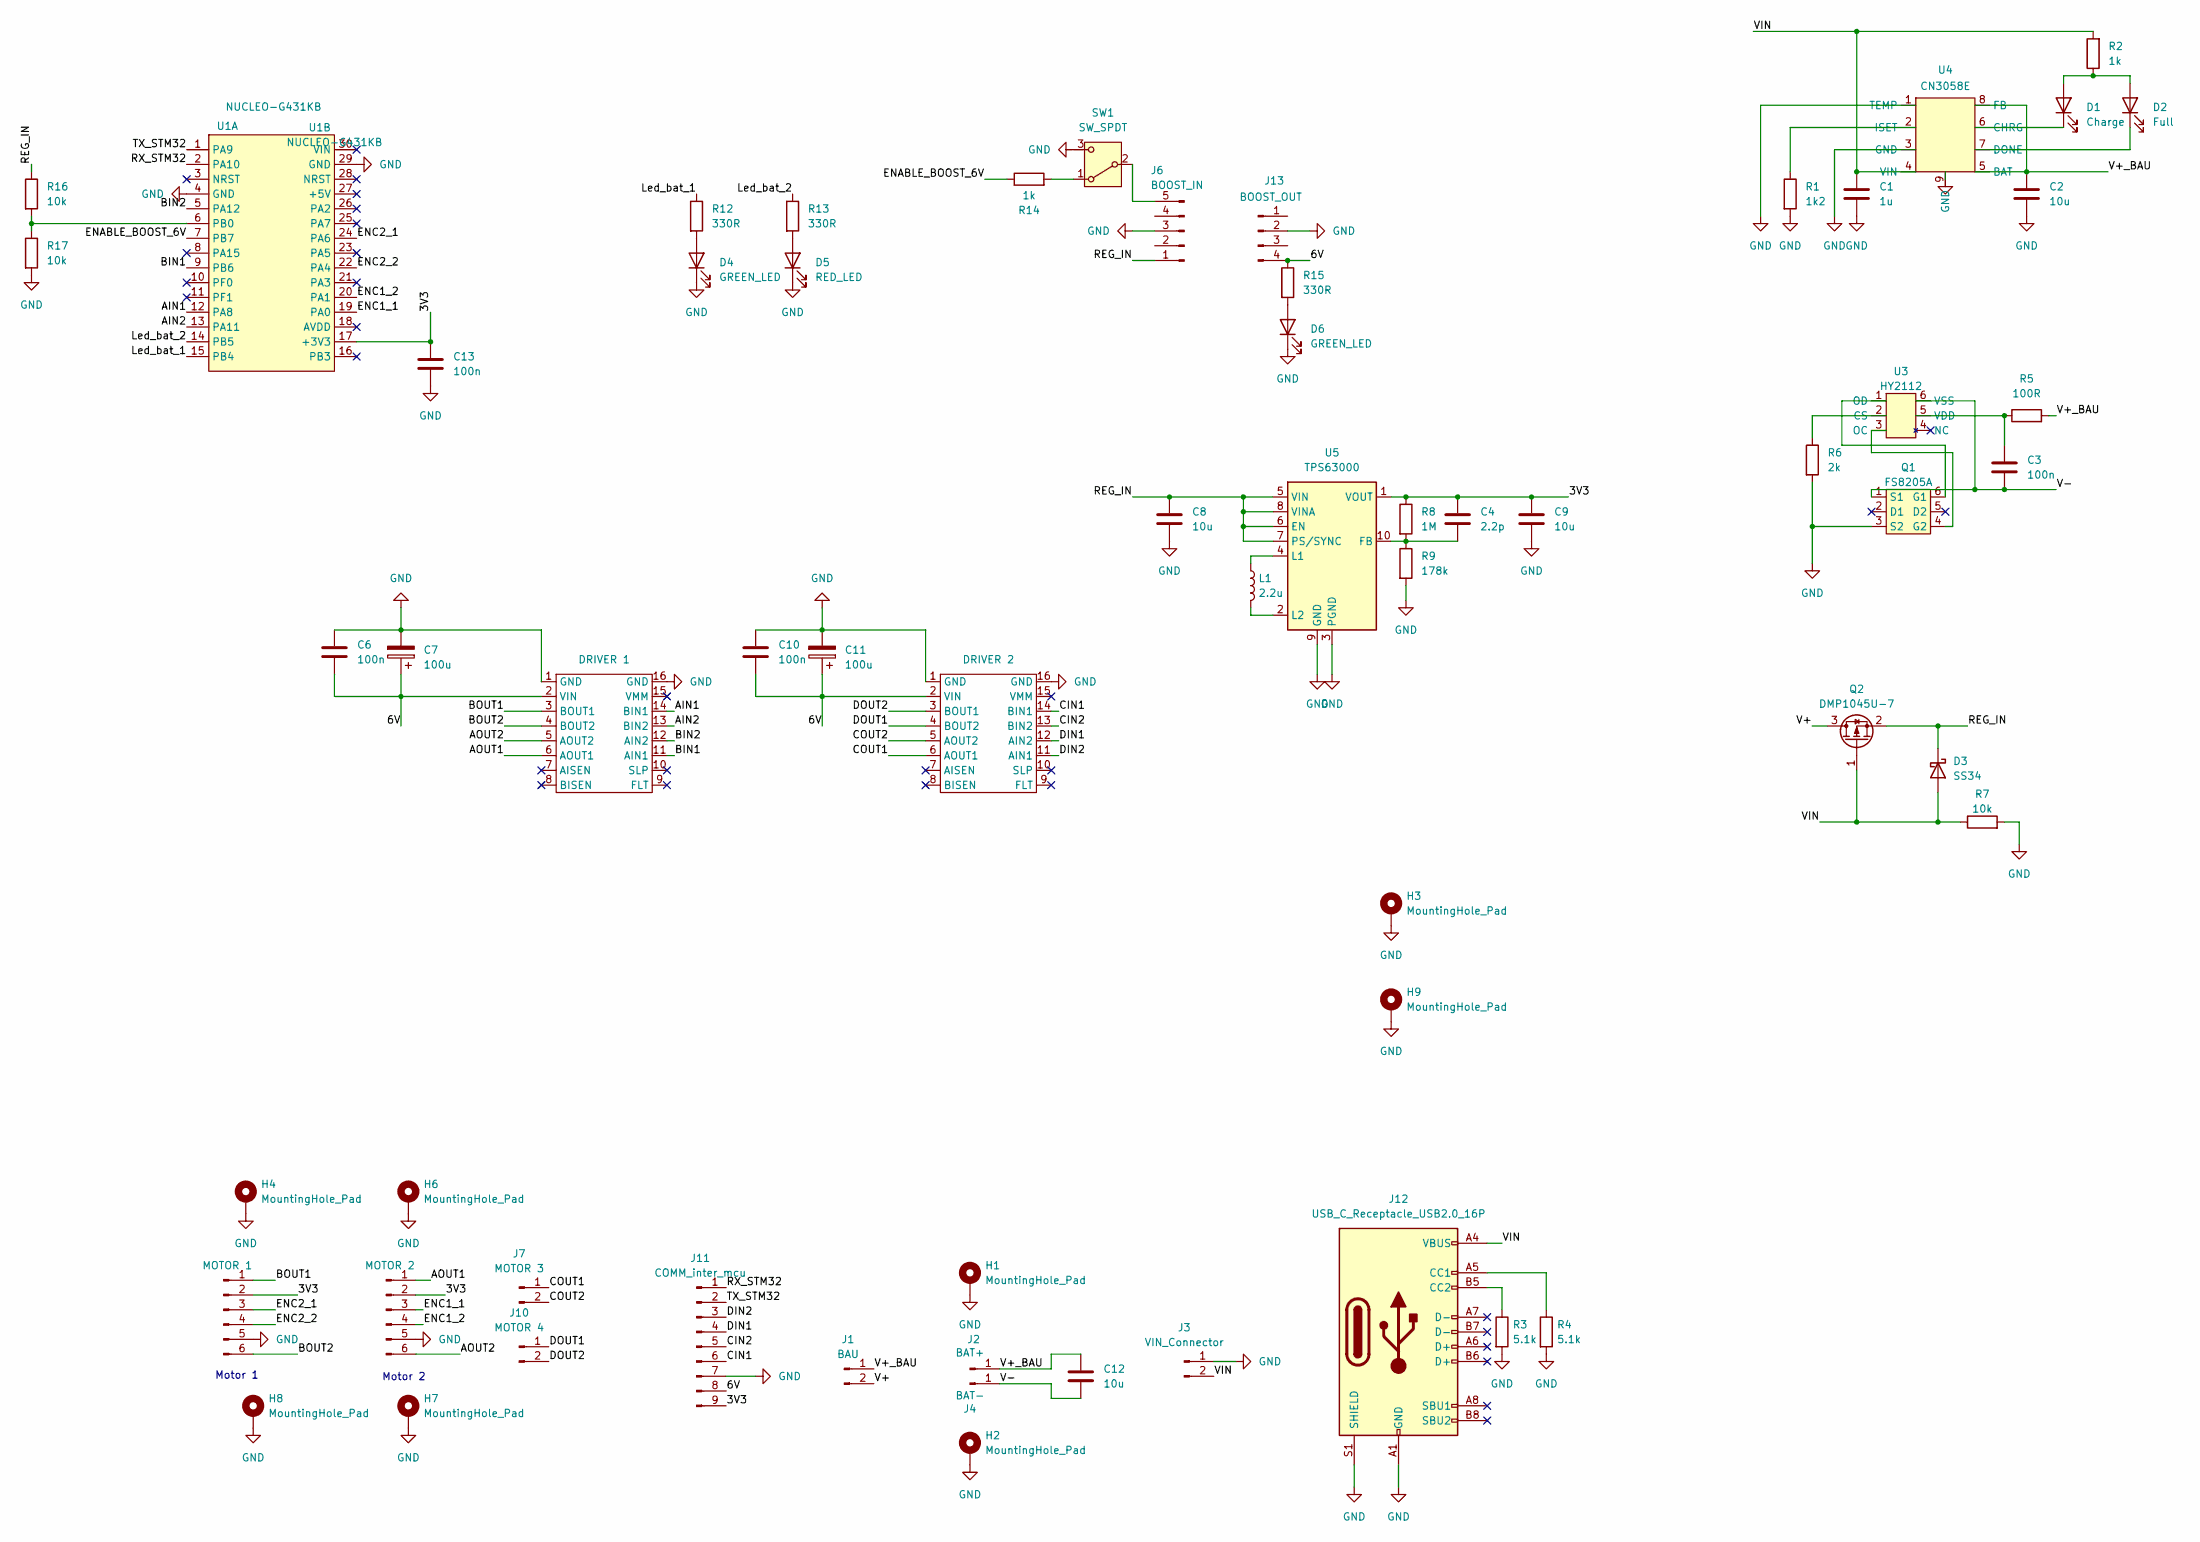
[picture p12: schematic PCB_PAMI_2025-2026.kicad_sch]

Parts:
C1: 1u; C_0603_1608Metric
C2, C8, C9, C12: 10u; C_0603_1608Metric
C3, C6, C10, C13: 100n; C_0603_1608Metric
C4: 2.2p; C_0603_1608Metric
C7, C11: 100u; CP_Elec_6.3x5.4
D1: Charge; LED_0603_1608Metric
D2: Full; LED_0603_1608Metric
D3: SS34; D_SMA
D4, D6: GREEN_LED; LED_0603_1608Metric
D5: RED_LED; LED_0603_1608Metric
H1, H2, H3, H4, H6, H7, H8, H9: MountingHole_Pad; MountingHole_3.2mm_M3_Pad_Via
J1: BAU; JST_VH_B2P-VH_1x02_P3.96mm_Vertical
J2: BAT+; TestPoint_THTPad_D2.5mm_Drill1.2mm
J3: VIN_Connector; TerminalBlock_Phoenix_MKDS-1,5-2-5.08_1x02_P5.08mm_Horizont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
J4: BAT-; TestPoint_THTPad_D2.5mm_Drill1.2mm
J6: BOOST_IN; PinSocket_1x05_P2.54mm_Vertical
J7: MOTOR 3; JST_VH_B2P-VH_1x02_P3.96mm_Vertical
J8: MOTOR 1; PinHeader_1x06_P2.54mm_Vertical
J9: MOTOR 2; PinHeader_1x06_P2.54mm_Vertical
J10: MOTOR 4; JST_VH_B2P-VH_1x02_P3.96mm_Vertical
J11: COMM_inter_mcu; PinSocket_1x09_P2.54mm_Vertical
J12: USB_C_Receptacle_USB2.0_16P; USB_C_Receptacle_HRO_TYPE-C-31-M-12
J13: BOOST_OUT; PinSocket_1x04_P2.54mm_Vertical
L1: 2.2u; L_Wuerth_WE-TPC-3816
Q1: FS8205A; SOT-23-6
Q2: DMP1045U-7; SOT-23
R1: 1k2; R_0603_1608Metric
R2, R14: 1k; R_0603_1608Metric
R3, R4: 5.1k; R_0603_1608Metric
R5: 100R; R_0603_1608Metric
R6: 2k; R_0603_1608Metric
R7, R16, R17: 10k; R_0603_1608Metric
R8: 1M; R_0603_1608Metric
R9: 178k; R_0603_1608Metric
R12, R13, R15: 330R; R_0603_1608Metric
SW1: SW_SPDT; SW_SPDT_PCM12
U1: NUCLEO-G431KB; Arduino_Nano
U2: DRIVER 1; DIP-16_W10.16mm_LongPads
U3: HY2112; SOT-23-6
U4: CN3058E; SOIC-8-1EP_3.9x4.9mm_P1.27mm_EP2.29x3mm
U5: TPS63000; Texas_DRC0010J_ThermalVias
U6: DRIVER 2; DIP-16_W10.16mm_LongPads

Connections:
/3V3: C4.1, C9.1, C13.1, J8.2, J9.2, J11.9, R8.1, U1.17 (+3V3), U5.1 (VOUT)
/6V: C6.2, C7.1, C10.2, C11.1, J11.8, J13.4, R15.1, U2.2 (VIN), U6.2 (VIN)
/AIN1: U1.12 (PA8), U2.14 (BIN1)
/AIN2: U1.13 (PA11), U2.13 (BIN2)
/AOUT1: J9.1, U2.6 (AOUT1)
/AOUT2: J9.6, U2.5 (AOUT2)
/BIN1: U1.9 (PB6), U2.11 (AIN1)
/BIN2: U1.5 (PA12), U2.12 (AIN2)
/BOUT1: J8.1, U2.3 (BOUT1)
/BOUT2: J8.6, U2.4 (BOUT2)
/CIN1: J11.6, U6.14 (BIN1)
/CIN2: J11.5, U6.13 (BIN2)
/COUT1: J7.1, U6.6 (AOUT1)
/COUT2: J7.2, U6.5 (AOUT2)
/DIN1: J11.4, U6.12 (AIN2)
/DIN2: J11.3, U6.11 (AIN1)
/DOUT1: J10.1, U6.4 (BOUT2)
/DOUT2: J10.2, U6.3 (BOUT1)
/ENABLE_BOOST_6V: R14.1, U1.7 (PB7)
/ENC1_1: J9.3, U1.19 (PA0)
/ENC1_2: J9.4, U1.20 (PA1)
/ENC2_1: J8.3, U1.24 (PA6)
/ENC2_2: J8.4, U1.22 (PA4)
/Led_bat_1: R12.1, U1.15 (PB4)
/Led_bat_2: R13.1, U1.14 (PB5)
/REG_IN: C8.1, D3.1 (K), J6.1, Q2.2 (S), R16.1, U5.5 (VIN), U5.6 (EN), U5.7 (PS/SYNC), U5.8 (VINA)
/RX_STM32: J11.1, U1.2 (PA10)
/TX_STM32: J11.2, U1.1 (PA9)
/V+: J1.2, Q2.3 (D)
/V+_BAU: C2.1, C12.1, J1.1, J2.1, R5.2, U4.5 (BAT), U4.8 (FB)
/V-: C3.2, C12.2, J4.1, Q1.1 (S1), U3.6 (VSS)
/VIN: C1.1, D3.2 (A), J3.2, J12.A4 (VBUS), J12.A9 (VBUS), J12.B4 (VBUS), J12.B9 (VBUS), Q2.1 (G), R2.2, R7.1, U4.4 (VIN)
GND: C1.2, C2.2, C6.1, C7.2, C8.2, C9.2, C10.1, C11.2, C13.2, D4.1 (K), D5.1 (K), D6.1 (K), H1.1, H2.1, H3.1, H4.1, H6.1, H7.1, H8.1, H9.1, J3.1, J6.3, J8.5, J9.5, J11.7, J12.A1 (GND), J12.A12 (GND), J12.B1 (GND), J12.B12 (GND), J12.S1 (SHIELD), J13.2, Q1.3 (S2), R1.2, R3.2, R4.2, R6.2, R7.2, R9.2, R17.2, SW1.3 (C), U1.4 (GND), U1.29 (GND), U2.1 (GND), U2.16 (GND), U4.1 (TEMP), U4.3 (GND), U4.9 (GND), U5.3 (PGND), U5.9 (GND), U5.11 (PGND), U6.1 (GND), U6.16 (GND)
unnamed: D1.2 (A), D2.2 (A), R2.1
unnamed: D1.1 (K), U4.6 (CHRG)
unnamed: D2.1 (K), U4.7 (DONE)
unnamed: D4.2 (A), R12.2
unnamed: D5.2 (A), R13.2
unnamed: D6.2 (A), R15.2
unnamed: J6.5, SW1.2 (B)
unnamed: J12.A5 (CC1), R4.1
unnamed: J12.B5 (CC2), R3.1
unnamed: Q1.6 (G1), U3.1 (OD)
unnamed: Q1.4 (G2), U3.3 (OC)
unnamed: R14.2, SW1.1 (A)
unnamed: R16.2, R17.1, U1.6 (PB0)
unnamed: R6.1, U3.2 (CS)
unnamed: C3.1, R5.1, U3.5 (VDD)
unnamed: R1.1, U4.2 (ISET)
unnamed: C4.2, R8.2, R9.1, U5.10 (FB)
unnamed: L1.1, U5.4 (L1)
unnamed: L1.2, U5.2 (L2)

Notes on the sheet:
Motor 1
Motor 2

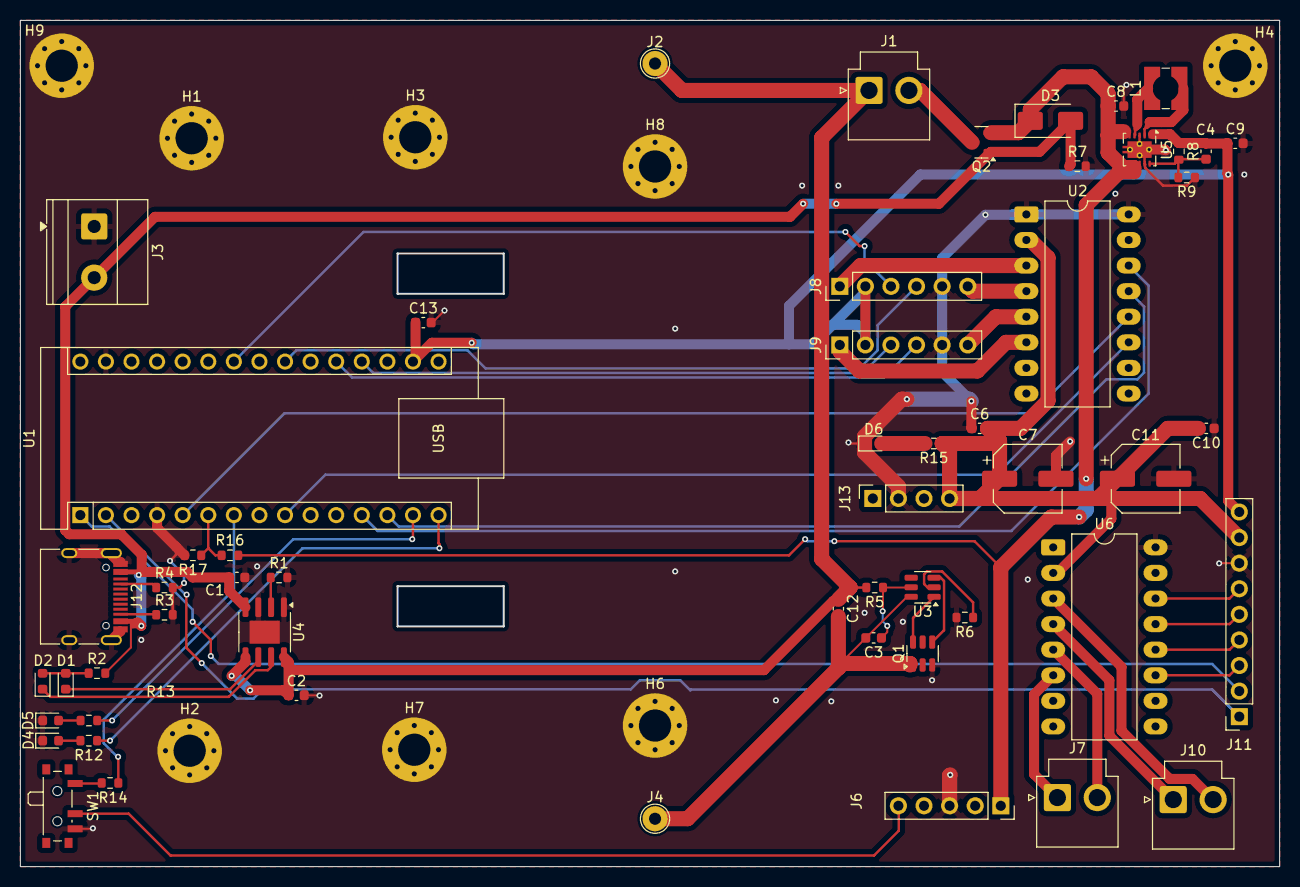
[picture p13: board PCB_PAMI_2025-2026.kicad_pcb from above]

Board: 2 copper layers, 125.0 x 84.0 mm, 63 parts (0 on the bottom side), 52 nets.

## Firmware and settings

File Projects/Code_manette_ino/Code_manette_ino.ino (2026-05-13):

// Code pour l'ESP32 - Contrôle robot PAMI par manette
#include <Arduino.h>
#include "pami_com.h"
#include <Bluepad32.h>
#include <ESP32Servo.h>

// ============================================
// DÉFINITION DES PINS (Actionneurs supplémentaires)
// ============================================
#define PIN_SERVO_1   19
#define PIN_SERVO_2   27
#define PIN_SERVO_3   15  
#define PIN_LED_DATA  14

// Moteurs directs ESP32
#define PIN_MOT1_DIR1  32
#define PIN_MOT1_DIR2  33
#define PIN_MOT2_DIR1  25
#define PIN_MOT2_DIR2  26

// ============================================
// VARIABLES GLOBALES
// ============================================
bool mode_auto = false;
float target_x = 0.0f, target_y = 0.0f;
float current_x = 0.0f, current_y = 0.0f;

// Manette Bluetooth
ControllerPtr myControllers[BP32_MAX_GAMEPADS];

// Paramètres de pilotage principal
const int JOYSTICK_DEADZONE = 50;
const int MAX_MOTOR_SPEED = 1000;

// --- VARIABLES D'ACCÉLÉRATION ET ANTI-PATINAGE MOTEURS ---
float current_motor1 = 0;
float current_motor2 = 0;
const float MAX_ACCEL_STEP = 40.0;

float current_smoothed_rx = 0.0f; 
const float MAX_ROTATION_STEP = 0.04f;

// ============================================
// VARIABLES SERVOMOTEURS (MODIFIÉ)
// ============================================
Servo servo1;
Servo servo2;
Servo servo3;

// 1. Angles Cibles (Ce que tu demandes avec la manette)
float targetServo1 = 63.0; 
float targetServo2 = 0.0;
float targetServo3 = 0.0; 

// 2. Angles Actuels (La position réelle lissée)
float currentServo1 = 63.0; 
float currentServo2 = 0.0;
float currentServo3 = 0.0;

// 3. VITESSE MAX DES SERVOS (Le paramètre qui sauve ta batterie !)
// Réactivité augmentée pour éviter que la position réelle prenne du retard sur la cible.
const float SERVO_MAX_STEP = 5.0; 

// ============================================
// CALLBACKS MANETTE
// ============================================
void onConnectedController(ControllerPtr ctl) {
  for (int i = 0; i < BP32_MAX_GAMEPADS; i++) {
    if (myControllers[i] == nullptr) {
      myControllers[i] = ctl;
      Serial.printf("Manette connectée à l'index %d\n", i);
      break;
    }
  }
}

void onDisconnectedController(ControllerPtr ctl) {
  for (int i = 0; i < BP32_MAX_GAMEPADS; i++) {
    if (myControllers[i] == ctl) {
      myControllers[i] = nullptr;
      Serial.printf("Manette déconnectée de l'index %d\n", i);
      break;
    }
  }
}

// ============================================
// SETUP
// ============================================
void setup() {
  initPAMI();
  BP32.setup(&onConnectedController, &onDisconnectedController);
  setModeManuel();
  
  // --- INITIALISATION DES SERVOS ---
  ESP32PWM::allocateTimer(0);
  ESP32PWM::allocateTimer(1);
  ESP32PWM::allocateTimer(2);
  
  servo1.setPeriodHertz(50);
  servo2.setPeriodHertz(50);
  servo3.setPeriodHertz(50);
  
  servo1.attach(PIN_SERVO_1, 500, 2400);
  servo2.attach(PIN_SERVO_2, 500, 2400);
  servo3.attach(PIN_SERVO_3, 500, 2400);
  
  // On écrit la position initiale
  servo1.write((int)currentServo1);
  servo2.write((int)currentServo2);
  servo3.write((int)currentServo3);

  // --- INITIALISATION DES MOTEURS DIRECTS ---
  pinMode(PIN_MOT1_DIR1, OUTPUT);
  pinMode(PIN_MOT1_DIR2, OUTPUT);
  pinMode(PIN_MOT2_DIR1, OUTPUT);
  pinMode(PIN_MOT2_DIR2, OUTPUT);
  pinMode(PIN_LED_DATA, OUTPUT);

  digitalWrite(PIN_MOT1_DIR1, LOW);
  digitalWrite(PIN_MOT1_DIR2, LOW);
  digitalWrite(PIN_MOT2_DIR1, LOW);
  digitalWrite(PIN_MOT2_DIR2, LOW);

  delay(5);
  resetSTM32();
  Serial.println("En attente de manette...");
}

// ============================================
// LOOP
// ============================================
void loop() {
  BP32.update();
  receiveFromSTM32(); 

  for (int i = 0; i < BP32_MAX_GAMEPADS; i++) {
    ControllerPtr ctl = myControllers[i];
    if (ctl && ctl->isConnected()) {
      
      int ly = ctl->axisY();   // Avant/Arrière
      int rx = ctl->axisRX();  // Rotation

      if (abs(ly) < JOYSTICK_DEADZONE) ly = 0;
      if (abs(rx) < JOYSTICK_DEADZONE) rx = 0;

      // 1. BOUTON RETURN TO HOME (Bouton X)
      if (ctl->x()) {
        if (!mode_auto) {
          mode_auto = true;
          setModeAuto();
          delay(5);
          sendPosition(0.0f, 0.0f);
          Serial.println(">> MODE AUTO : Retour à la base (0,0) !");
        }
      }

      // 2. REPRISE MANUELLE & PILOTAGE
      if (ly != 0 || rx != 0) {
        if (mode_auto) {
          mode_auto = false;
          setModeManuel();
          Serial.println(">> MODE MANUEL : Reprise du contrôle !");
        }
      }

      if (!mode_auto) {
        // --- GESTION DU BOOST (Bouton Y) ---
        float current_max_speed = 400;
        if (ctl->y()) { 
            current_max_speed = MAX_MOTOR_SPEED; 
        }

        // --- MODIFICATION DES CIBLES SERVOS 1 & 2 (Main Gauche) ---
        if (ctl->l1()) { // LT
          targetServo1 += 2.0; 
          targetServo2 -= 2.0; 
        }
        if (ctl->brake() > JOYSTICK_DEADZONE) { // LB 
          targetServo1 -= 2.0;
          targetServo2 += 2.0; 
        }

        // --- MODIFICATION DE LA CIBLE SERVO 3 (Main Droite) ---
        if (ctl->r1()) { // RT 
            targetServo3 -= 2.0; 
        }
        if (ctl->throttle() > JOYSTICK_DEADZONE) { // RB 
            targetServo3 += 2.0;
        }

        // Sécurité Butées sur les Cibles
        targetServo1 = constrain(targetServo1, 63.0, 180.0);
        targetServo2 = constrain(targetServo2, 0.0, 180.0);
        targetServo3 = constrain(targetServo3, 0.0, 180.0);

        // ========================================================
        // LE SOFT-START (LA MAGIE ANTI-COUPURE BATTERIE)
        // ========================================================
        if (targetServo1 > currentServo1) currentServo1 = min(targetServo1, currentServo1 + SERVO_MAX_STEP);
        else if (targetServo1 < currentServo1) currentServo1 = max(targetServo1, currentServo1 - SERVO_MAX_STEP);

        if (targetServo2 > currentServo2) currentServo2 = min(targetServo2, currentServo2 + SERVO_MAX_STEP);
        else if (targetServo2 < currentServo2) currentServo2 = max(targetServo2, currentServo2 - SERVO_MAX_STEP);

        if (targetServo3 > currentServo3) currentServo3 = min(targetServo3, currentServo3 + SERVO_MAX_STEP);
        else if (targetServo3 < currentServo3) currentServo3 = max(targetServo3, currentServo3 - SERVO_MAX_STEP);

        // --- ÉCRITURE ANTI-VIBRATION ---
        static int last_s1 = -1;
        static int last_s2 = -1;
        static int last_s3 = -1;
        
        int out_s1 = (int)currentServo1;
        int out_s2 = (int)currentServo2;
        int out_s3 = (int)currentServo3;

        if (out_s1 != last_s1) { servo1.write(out_s1); last_s1 = out_s1; }
        if (out_s2 != last_s2) { servo2.write(out_s2); last_s2 = out_s2; }
        if (out_s3 != last_s3) { servo3.write(out_s3); last_s3 = out_s3; }

        // --- CONTRÔLE DES MOTEURS ESP32 (Mode Tank sur D-PAD) ---
        uint8_t dpad = ctl->dpad();
        
        if (dpad & 0x01) { 
            digitalWrite(PIN_MOT1_DIR1, HIGH); digitalWrite(PIN_MOT1_DIR2, LOW);
            digitalWrite(PIN_MOT2_DIR1, HIGH); digitalWrite(PIN_MOT2_DIR2, LOW);
        } 
        else if (dpad & 0x02) { 
            digitalWrite(PIN_MOT1_DIR1, LOW); digitalWrite(PIN_MOT1_DIR2, HIGH);
            digitalWrite(PIN_MOT2_DIR1, LOW); digitalWrite(PIN_MOT2_DIR2, HIGH);
        } 
        else if (dpad & 0x08) { 
            digitalWrite(PIN_MOT1_DIR1, LOW); digitalWrite(PIN_MOT1_DIR2, HIGH);
            digitalWrite(PIN_MOT2_DIR1, HIGH); digitalWrite(PIN_MOT2_DIR2, LOW);
        } 
        else if (dpad & 0x04) { 
            digitalWrite(PIN_MOT1_DIR1, HIGH); digitalWrite(PIN_MOT1_DIR2, LOW);
            digitalWrite(PIN_MOT2_DIR1, LOW); digitalWrite(PIN_MOT2_DIR2, HIGH);
        } 
        else { 
            digitalWrite(PIN_MOT1_DIR1, LOW); digitalWrite(PIN_MOT1_DIR2, LOW);
            digitalWrite(PIN_MOT2_DIR1, LOW); digitalWrite(PIN_MOT2_DIR2, LOW);
        }

        // --- COURBES ET ANTI-PATINAGE EN ROTATION (Moteurs Principaux) ---
        float target_ly = (float)ly / 512.0f;
        float target_rx = (float)rx / 512.0f;
        
        target_ly = target_ly * target_ly * target_ly;
        target_rx = target_rx * target_rx * target_rx;

        if (target_rx > current_smoothed_rx) {
          current_smoothed_rx = min(target_rx, current_smoothed_rx + MAX_ROTATION_STEP);
        } else {
          current_smoothed_rx = max(target_rx, current_smoothed_rx - MAX_ROTATION_STEP);
        }

        float adjusted_ly = target_ly * (1.0 - abs(current_smoothed_rx) * 0.7);

        float target_m1 = (current_smoothed_rx + adjusted_ly) * current_max_speed;
        float target_m2 = (current_smoothed_rx - adjusted_ly) * current_max_speed;

        // CORRECTION MATÉRIELLE
        target_m1 = target_m1; 

        target_m1 = constrain(target_m1, -current_max_speed, current_max_speed);
        target_m2 = constrain(target_m2, -current_max_speed, current_max_speed);

        // --- RAMPE D'ACCÉLÉRATION FINALE ---
        if (target_m1 > current_motor1) current_motor1 = min((float)target_m1, current_motor1 + MAX_ACCEL_STEP);
        else current_motor1 = max((float)target_m1, current_motor1 - MAX_ACCEL_STEP);

        if (target_m2 > current_motor2) current_motor2 = min((float)target_m2, current_motor2 + MAX_ACCEL_STEP);
        else current_motor2 = max((float)target_m2, current_motor2 - MAX_ACCEL_STEP);

        // Envoi à la STM32
        sendMotors((int16_t)current_motor1, (int16_t)current_motor2);
      }
    }
  }
  receiveFromSTM32();
  delay(20);  // ~50Hz
}

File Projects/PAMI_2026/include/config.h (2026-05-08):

#ifndef CONFIG_H
#define CONFIG_H

#include <Arduino.h>

// --- PINS DEFINITIONS ---
// UART STM32
#define PIN_RX2       16
#define PIN_TX2       17

// I2C SENSORS
#define PIN_SDA       21
#define PIN_SCL       22
// TOF XSHUT (LPN)
#define PIN_TOF1_LPN  4
#define PIN_TOF2_LPN  23
#define PIN_TOF3_LPN  18

// Actionneurs
#define PIN_SERVO_1   19
#define PIN_SERVO_2   15
#define PIN_SERVO_3   27
#define PIN_LED_DATA  14
#define PIN_MOT1_DIR1  32 // Moteur direct 1
#define PIN_MOT1_DIR2  33
#define PIN_MOT2_DIR1  25 // Moteur direct 2
#define PIN_MOT2_DIR2  26

// INPUTS
#define PIN_TIRETTE   39 // À définir (Pull-up interne requis)
#define PIN_SW_COLOR  34 // Input Only
#define PIN_SW_DEBUG  35 // Input Only
#define PIN_SW_MODE   36 // "UP" - Souvent VP/VN (Input Only)

// --- CONSTANTS ---
#define MATCH_DURATION_MS 99000 // 99 secondes (marge sécu)
#define BATTERY_MIN_V     3.0f  // Seuil alerte (par cellule, ou total à adapter)
#define BATTERY_TIMEOUT   1000  // Temps min sous le seuil pour déclencher l'erreur

// --- TOF GEOMETRY (Matriciels 8x8) ---
// Ordre des capteurs dans le code : [0]=TOF2(Gauche), [1]=TOF3(Centre), [2]=TOF1(Droite)
// On lit uniquement la ligne du milieu pour économiser la puissance GPU
// Angles en degrés, orientation : 0°=devant, +90°=gauche, -90°=droite (convention robot)

#define TOF_ANGLE_GAUCHE  -55.5f  // TOF2 : tourné 55.5° à gauche
#define TOF_FOV_GAUCHE    60.0f   // 60° de champ

#define TOF_ANGLE_CENTRE  0.0f    // TOF3 : au centre
#define TOF_FOV_CENTRE    45.0f   // 45° de champ

#define TOF_ANGLE_DROITE  55.5f   // TOF1 : tourné 55.5° à droite
#define TOF_FOV_DROITE    60.0f   // 60° de champ

// Paramètres de la matricielle : on lit seulement la ligne du milieu (8 zones par capteur)
#define TOF_ZONES_PER_LINE 8
#define TOF_LINE_MIDDLE    4      // Indice de la ligne du milieu dans la matrice 8x8

#endif

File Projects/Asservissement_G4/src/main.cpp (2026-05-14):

#include "main.hpp"
#include "tim.h"
#include "usart.h"
#include "gpio.h"
#include "adc.h"
#include "control/motor.hpp"
#include "control/odometry.hpp"
#include "control/asservissement.hpp"
#include "utils/printf.hpp"
#include <cstring>
#include <array>

void SystemClock_Config(void);
void HAL_TIM_PeriodElapsedCallback(TIM_HandleTypeDef *htim);

// Instance de SerialOut pour la communication UART
SerialOut serial;

// Variables globales
uint8_t rxByte;
char cmd_buffer[50] = {0};
uint8_t cmd_idx = 0;

// Variables ADC
uint32_t adc_values;  // variable pour stocker les valeurs ADC

// Seuils de tension pour LEDs batterie (après pont diviseur /2)
// LiFePO4 1S: pleine charge ~3.6V -> 1.8V, déchargée ~2.5V -> 1.25V
// USB 5V -> 2.5V
#define BATTERY_FULL_THRESHOLD     1.6f   // Tension seuil batterie bien chargée (V après diviseur) = 3.2V réel
#define BATTERY_LOW_THRESHOLD      1.45f  // Tension seuil batterie faible (V après diviseur) = 2.9V réel
#define BATTERY_CRITICAL_THRESHOLD 1.35f  // Tension critique (V après diviseur) = 2.7V réel
#define USB_VOLTAGE_MAX            2.55f  // Tension USB max (5V / 2 = 2.5V)
#define USB_VOLTAGE_MIN            2.4f   // Tension USB min

// Fonction pour mettre à jour les LEDs de batterie
void update_battery_leds(float voltage) {
    static uint32_t blink_timer = 0;
    static bool blink_state = false;
    
    // Si tension USB (~2.5V après diviseur) -> les deux LEDs allumées
    if (voltage >= USB_VOLTAGE_MIN && voltage <= USB_VOLTAGE_MAX) {
        HAL_GPIO_WritePin(GPIOB, GPIO_PIN_4, GPIO_PIN_RESET);  // LED verte OFF
        HAL_GPIO_WritePin(GPIOB, GPIO_PIN_5, GPIO_PIN_RESET);  // LED rouge OFF
    }
    // Batterie dangereusement basse -> LED rouge clignotante
    else if (voltage < BATTERY_CRITICAL_THRESHOLD) {
        HAL_GPIO_WritePin(GPIOB, GPIO_PIN_4, GPIO_PIN_RESET); // LED verte OFF
        // Clignotement toutes les 250ms
        if (HAL_GetTick() - blink_timer >= 250) {
            blink_state = !blink_state;
            blink_timer = HAL_GetTick();
        }
        HAL_GPIO_WritePin(GPIOB, GPIO_PIN_5, blink_state ? GPIO_PIN_SET : GPIO_PIN_RESET);
    }
    // Batterie faible (entre critical et low) -> LED rouge seule
    else if (voltage < BATTERY_LOW_THRESHOLD) {
        HAL_GPIO_WritePin(GPIOB, GPIO_PIN_4, GPIO_PIN_RESET); // LED verte OFF
        HAL_GPIO_WritePin(GPIOB, GPIO_PIN_5, GPIO_PIN_SET);   // LED rouge ON
    }
    // Batterie moyenne (entre low et full) -> les deux LEDs
    else if (voltage < BATTERY_FULL_THRESHOLD) {
        HAL_GPIO_WritePin(GPIOB, GPIO_PIN_4, GPIO_PIN_SET);  // LED verte ON
        HAL_GPIO_WritePin(GPIOB, GPIO_PIN_5, GPIO_PIN_SET);  // LED rouge ON
    }
    // Batterie bien chargée -> LED verte seule
    else {
        HAL_GPIO_WritePin(GPIOB, GPIO_PIN_4, GPIO_PIN_SET);  // LED verte ON
        HAL_GPIO_WritePin(GPIOB, GPIO_PIN_5, GPIO_PIN_RESET); // LED rouge OFF
    }
}

// Mode de fonctionnement : true = test manuel, false = asservi
bool test_mode = true;

// Moteurs utilisant la classe Wheel
std::array<Wheel, 3> wheels = {
    Wheel(1, 600, 21.5f, 0.0f),     // Moteur 1
    Wheel(2, 600, 21.5f, 0.0f),   // Moteur 2
    Wheel(3, 600, 21.5f, 0.0f)      // Moteur 3 (réserve)
};

// Odométrie et asservissement
Odometry odometry(wheels);
Asserv_Position asserv(&odometry, &wheels);

// Variables pour la position cible
float target_x = 0.0f;
float target_y = 0.0f;
float target_z = 0.0f;  // Rotation en degrés

// Compteur pour l'affichage périodique
static uint32_t lastSend = 0;

// Timer pour redémarrage asserv 1s après réception de commande pos
static uint32_t asserv_restart_time = 0;

int main(void)
{
    HAL_Init();
    SystemClock_Config();

    // Initialisation des périphériques
    MX_GPIO_Init();
    MX_TIM1_Init();
    MX_TIM2_Init();
    MX_TIM3_Init();
    MX_TIM6_Init();
    MX_TIM15_Init();
    MX_TIM16_Init();
    MX_TIM17_Init();
    MX_USART1_UART_Init();
    MX_ADC1_Init();
    MX_ADC2_Init();

    // Calibration ADC - IMPORTANT: avant toute utilisation
    if (HAL_ADCEx_Calibration_Start(&hadc1, ADC_SINGLE_ENDED) != HAL_OK) {
        serial.send("Erreur calibration ADC1\r\n");
    }
    if (HAL_ADCEx_Calibration_Start(&hadc2, ADC_SINGLE_ENDED) != HAL_OK) {
        serial.send("Erreur calibration ADC2\r\n");
    }

    // Initialisation des encodeurs au milieu (32768)
    TIM2->CNT = (1<<15);
    TIM3->CNT = (1<<15);

    // Démarrage des encodeurs
    HAL_TIM_Encoder_Start(&htim2, TIM_CHANNEL_ALL);
    HAL_TIM_Encoder_Start(&htim3, TIM_CHANNEL_ALL);

    // Démarrage des PWM moteurs avec canaux complémentaires
    HAL_TIM_PWM_Start(&htim1, TIM_CHANNEL_1);       // Moteur 1 CH1
    HAL_TIMEx_PWMN_Start(&htim1, TIM_CHANNEL_1);    // Moteur 1 CH1N
    HAL_TIM_PWM_Start(&htim16, TIM_CHANNEL_1);      // Moteur 2 CH1
    HAL_TIMEx_PWMN_Start(&htim16, TIM_CHANNEL_1);   // Moteur 2 CH1N

    __HAL_TIM_MOE_ENABLE(&htim1);
    __HAL_TIM_MOE_ENABLE(&htim16);
    //__HAL_TIM_MOE_ENABLE(&htim8);

    // Initialiser les moteurs à 0
    wheels[0].set_pwm(0);
    wheels[1].set_pwm(0);

    // Démarrage réception UART
    HAL_UART_Receive_IT(&huart1, &rxByte, 1);

    // Démarrage des timers pour interruptions
    // TIM6 : Odométrie 500Hz
    // TIM15 : Timer générique 1Hz
    // TIM17 : Asservissement 100Hz
    HAL_TIM_Base_Start_IT(&htim6);
    HAL_TIM_Base_Start_IT(&htim15);
    HAL_TIM_Base_Start_IT(&htim17);

    // Configuration PID pour l'asservissement en position
    asserv.set_PID(6.0, 6.0, 4.0);

    // Message de démarrage
    serial.send("\r\n=== PAMI STM32 ===\r\n");
    serial.send("mode auto   -> Mode automatique\r\n");
    serial.send("mode manuel -> Mode manuel\r\n");
    serial.send("AUTO: X:xxx Y:xxx (mm)\r\n");
    serial.send("MANUEL: M1:xxx M2:xxx (-1000/+1000), on, off, stop\r\n");
    serial.send("==================\r\n\r\n");

    while (1) {
        // Vérifier si l'asserv doit redémarrer (1s après réception commande pos)
        if (asserv_restart_time != 0 && HAL_GetTick() >= asserv_restart_time) {
            asserv.start_asserv();
            asserv_restart_time = 0;
        }

        // Affichage toutes les 500ms (dans les deux modes)
        if (HAL_GetTick() - lastSend > 500) {
            
            // Lecture des encodeurs et vitesses
            int32_t enc1 = wheels[0].get_encoder_count();
            int32_t enc2 = wheels[1].get_encoder_count();
            float speed1 = wheels[0].get_speed();
            float speed2 = wheels[1].get_speed();
            
            // --- CONVERSION EN MM/S (Plus lisible) ---
            // V = omega * R
            int32_t speed1_mm_s = (int32_t)(speed1 * 21.5f);
            int32_t speed2_mm_s = (int32_t)(speed2 * 21.5f);
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

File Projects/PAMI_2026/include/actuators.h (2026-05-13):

#ifndef ACTUATORS_H
#define ACTUATORS_H

#include <Arduino.h>
#include <ESP32Servo.h>
#include "config.h"

// ============================================
// OBJETS SERVOS
// ============================================
static Servo servo1;
static Servo servo2;
static Servo servo3;

// ============================================
// CONFIGURATION MOTEURS DC
// ============================================
#define MOTOR_PWM_FREQ  20000  // 20kHz pour éviter le bruit audible
#define MOTOR_PWM_RES   8      // 8 bits (0-255)

// Canaux LEDC pour les moteurs (les servos utilisent les canaux 0-2 via ESP32Servo)
#define LEDC_CH_MOT1_DIR1  4
#define LEDC_CH_MOT1_DIR2  5
#define LEDC_CH_MOT2_DIR1  6
#define LEDC_CH_MOT2_DIR2  7

// ============================================
// FONCTIONS SERVOS
// ============================================

/**
 * Initialise les 3 servos
 */
inline void initServos() {
    servo1.attach(PIN_SERVO_1);
    servo2.attach(PIN_SERVO_2);
    servo3.attach(PIN_SERVO_3);
}

/**
 * Positionne un servo à un angle donné (0-180°)
 * @param servo Numéro du servo (1, 2 ou 3)
 * @param angle Angle en degrés (0-180)
 */
inline void setServoAngle(uint8_t servo, uint8_t angle) {
    switch (servo) {
        case 1: servo1.write(angle); break;
        case 2: servo2.write(angle); break;
        case 3: servo3.write(angle); break;
    }
}

/**
 * Positionne un servo avec une valeur en microsecondes (500-2500µs)
 * @param servo Numéro du servo (1, 2 ou 3)
 * @param us Pulse en microsecondes
 */
inline void setServoMicroseconds(uint8_t servo, uint16_t us) {
    switch (servo) {
        case 1: servo1.writeMicroseconds(us); break;
        case 2: servo2.writeMicroseconds(us); break;
        case 3: servo3.writeMicroseconds(us); break;
    }
}

/**
 * Désactive un servo (libère le signal PWM)
 */
inline void disableServo(uint8_t servo) {
    switch (servo) {
        case 1: servo1.detach(); break;
        case 2: servo2.detach(); break;
        case 3: servo3.detach(); break;
    }
}

// ============================================
// FONCTIONS MOTEURS DC
// ============================================

/**
 * Initialise les 2 moteurs DC (pont H avec PWM)
 */
inline void initMotors() {
    // Moteur 1
    ledcSetup(LEDC_CH_MOT1_DIR1, MOTOR_PWM_FREQ, MOTOR_PWM_RES);
    ledcSetup(LEDC_CH_MOT1_DIR2, MOTOR_PWM_FREQ, MOTOR_PWM_RES);
    ledcAttachPin(PIN_MOT1_DIR1, LEDC_CH_MOT1_DIR1);
    ledcAttachPin(PIN_MOT1_DIR2, LEDC_CH_MOT1_DIR2);
    // Moteur 2
    ledcSetup(LEDC_CH_MOT2_DIR1, MOTOR_PWM_FREQ, MOTOR_PWM_RES);
    ledcSetup(LEDC_CH_MOT2_DIR2, MOTOR_PWM_FREQ, MOTOR_PWM_RES);
    ledcAttachPin(PIN_MOT2_DIR1, LEDC_CH_MOT2_DIR1);
    ledcAttachPin(PIN_MOT2_DIR2, LEDC_CH_MOT2_DIR2);
    
    // Arrêt initial
    ledcWrite(LEDC_CH_MOT1_DIR1, 0);
    ledcWrite(LEDC_CH_MOT1_DIR2, 0);
    ledcWrite(LEDC_CH_MOT2_DIR1, 0);
    ledcWrite(LEDC_CH_MOT2_DIR2, 0);
}

/**
 * Contrôle un moteur DC
 * @param motor Numéro du moteur (1 ou 2)
 * @param speed Vitesse de -255 à +255 (négatif = arrière)
 */
inline void setMotorSpeed(uint8_t motor, int16_t speed) {
    if (speed > 255) speed = 255;
    if (speed < -255) speed = -255;
    
    uint8_t pwm = abs(speed);
    
    if (motor == 1) {
        if (speed > 0) {
            ledcWrite(LEDC_CH_MOT1_DIR1, pwm);
            ledcWrite(LEDC_CH_MOT1_DIR2, 0);
        } else if (speed < 0) {
            ledcWrite(LEDC_CH_MOT1_DIR1, 0);
            ledcWrite(LEDC_CH_MOT1_DIR2, pwm);
        } else {
            ledcWrite(LEDC_CH_MOT1_DIR1, 0);
            ledcWrite(LEDC_CH_MOT1_DIR2, 0);
        }
    } else if (motor == 2) {
        if (speed > 0) {
            ledcWrite(LEDC_CH_MOT2_DIR1, pwm);
            ledcWrite(LEDC_CH_MOT2_DIR2, 0);
        } else if (speed < 0) {
            ledcWrite(LEDC_CH_MOT2_DIR1, 0);
            ledcWrite(LEDC_CH_MOT2_DIR2, pwm);
        } else {
            ledcWrite(LEDC_CH_MOT2_DIR1, 0);
            ledcWrite(LEDC_CH_MOT2_DIR2, 0);
        }
    }
}

/**
 * Contrôle les deux moteurs simultanément (pour conduite différentielle)
 * @param speedLeft Vitesse moteur gauche (-255 à +255)
 * @param speedRight Vitesse moteur droite (-255 à +255)
 */
inline void setMotors(int16_t speedLeft, int16_t speedRight) {
    setMotorSpeed(1, speedLeft);
    setMotorSpeed(2, speedRight);
}


#endif

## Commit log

2025-06-29 rajout de l'IHM et correctifs mineurs
    [IHM_PAMI_2026.py, main.cpp]
2025-06-29 historique des points gardé
2025-06-29 ajout reset des points lors du reste de la carte
    [IHM_PAMI_2026.py]
2025-06-29 rajout timer temps réel
2025-06-29 test du reset à ârtir du BT ok
    [main.cpp, python_lecture_esp32.py]
2025-07-05 bug de pin résolu
    [main.cpp]
2025-09-27 rajout code test de l'asservissement sur stm32
2025-09-27 adaptation de l'asserv avec les timers stm
2025-10-08 marche avec interruption mais sans PID, juste commande
2025-10-09 code censé être fonctionnel avec timers
2025-10-09 fonctionne bien avec moteur droit, PID vitesse OK
2025-10-16 implémentation du moteur gauche sur le timer 3, non fonctionnel
2025-10-16 les deux moteurs tournent mais pas à l'échelle
2025-10-23 lecture de l'encodeur gauche OK, rajout de la doc technique
2025-11-20 petit code de contrôle de led
2025-11-20 communication UART fonctionnelle, clignotement de led OK
2025-11-27 correction délaration tiler 16 + amélioration code contrôle moteur
    [motor.cpp]
2025-11-27 main.cpp minimal pour tester les encodeurs et le pwm
2025-11-27 adaptation code communication uart esp32
2025-11-27 ajout de la mesure de la tension au code de test main.cpp, mesures cohérentes
2025-11-27 code uart séparé pour lisibilité, test OK
2025-11-27 rajout d'un mode de test pour switcher entre le contrôle des moteurs par l'uart et l'asservissement normal
2025-11-27 esp32 adaptation mode asservisssement position
2025-11-27 correction mode esp32
2025-11-27 switch mode pas encore fonctionnel
2025-12-13 ajout du PCB de la carte de puissance/motorisation
    [PCB_PAMI_2025-2026.kicad_pcb, PCB_PAMI_2025-2026.kicad_sch, bom.csv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]
2025-12-13 ajout des via pour mieux relier les plans de masses
    [PCB_PAMI_2025-2026.kicad_pcb]
2025-12-13 création de la BOM et des fichiers nécéssaires pour JLCPCB
2025-12-14 petits changements fichiers kicad
2025-12-14 correction schéma driver + rajout via gnd
    [PCB_PAMI_2025-2026.kicad_pcb, PCB_PAMI_2025-2026.kicad_sch]
2025-12-15 corrections pins drivers trop proches
    [PCB_PAMI_2025-2026.kicad_pcb]
2025-12-15 ajustement de l'emplacement de certaines pièces
    [PCB_PAMI_2025-2026.kicad_pcb]
2025-12-18 exportation fichier step + petites modifs
    [PCB_PAMI_2025-2026.step, positions.csv]
2025-12-20 début du pcb principal, contrôle des capteurs tofs et actionneurs
    [MAIN_PCB_TOFS.kicad_pcb, MAIN_PCB_TOFS.kicad_sch]
2025-12-20 ajout de quelques éléments au pcb
    [MAIN_PCB_TOFS.kicad_sch]
2025-12-20 début du schéma électrique
    [MAIN_PCB_TOFS.kicad_pcb, MAIN_PCB_TOFS.kicad_sch]
2026-01-19 modification de l'allocation des pins (ajout contrôle led état), + modif auto pcb
    [PCB_PAMI_2025-2026.kicad_pcb]
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2026-01-20 simplification du protocole de communication entre les deux microncontrôlleurs (mode manuel/auto)
2026-01-22 correction affichage tension batterie (testée sur carte)
    [gpio.c]
2026-01-22 correction de la communication uart (cast des float en int)
    [main.cpp]
2026-01-22 code de lecture des tofs matriciels (non testé)
2026-01-23 ajout des switch, des tofs et mise en place des capa de découplage sur le pcb logique
    [MAIN_PCB_TOFS.kicad_sch]
2026-01-23 petites modifs kicad
    [MAIN_PCB_TOFS.kicad_pcb, MAIN_PCB_TOFS.kicad_sch]
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2026-01-24 organisation du pcb IHM pour préparer le routage
    [MAIN_PCB_TOFS.kicad_pcb, MAIN_PCB_TOFS.kicad_sch]
2026-01-25 modifications finales du pcb, problème sens capteurs tofs à régler
    [MAIN_PCB_TOFS.kicad_pcb, MAIN_PCB_TOFS.kicad_sch]
2026-01-25 finalisation du pcb et création des fichiers nécéssaires
    [MAIN_PCB_TOFS.kicad_pcb, PCB_PAMI_2025-2026.kicad_pcb]
2026-01-27 changement de la forme du pcb
    [MAIN_PCB_TOFS.kicad_pcb]
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2026-01-30 correction sens des roues et lecture des encodeurs
    [main.cpp, motor.cpp]
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2026-01-30 calcul de l'odométrie en cours de correction
    [main.cpp]
2026-01-30 correction de l'odométrie
2026-01-30 correction envoi des coordonnées, PID à régler
    [main.cpp, motor.cpp]
2026-01-31 ihm maj pour le nouveau protocole de communication
2026-01-31 asservissement un peu corrigé mais toujours lent
    [asservissement.cpp, main.cpp]
2026-01-31 correction sens de rotation, limite d'accélération
    [asservissement.cpp]
2026-02-01 amélioration de l'asservissement en position, implémentation de l'asser en vitesse à faire
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2026-02-01 correction timer début
2026-02-01 ajout correction d'angle pendant le déplacement linéaire
    [asservissement.cpp]
2026-02-03 code esp32 plus rapide, asser en rotation amélioré
2026-02-04 simplification du code principal de l'esp32, à tester sur carte
2026-02-05 reset de l'intégrateur lorsqu'une nouvelle cible est donnée
    [asservissement.cpp]
2026-02-05 amélioration de la vitesse et du suivi des coordonnées
2026-02-12 ajout modélisation 3D pcb tof
    [MAIN_PCB_TOFS.stl]
2026-02-12 copie de l'ancien code des pami légèrement adapté
2026-02-12 changement de la struscure du code de l'esp32 (passage sous freertos plus explicite)
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2026-02-28 adaptation du code des moteurs pour le sens inverse (pas l'odométrie encore)
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2026-03-10 ajout contrôle de la led rgb et état debug
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2026-03-10 correction pin tirette + ajout état manuel
    [config.h, task_strategy.cpp]
2026-05-04 maj de la couleur du terrain en continu
2026-05-04 correction tirette
2026-05-05 reset coord stm32 ok
    [main.cpp, task_strategy.cpp]
2026-05-05 évite les saut d'encodeurs trop élevés, règle le pb des coord d'orignie fausses
2026-05-06 mode erreur pour les tofs non initialisés, implémentation arrêt d'urgence en cours
2026-05-06 résolution du problème de l'init des tofs (pas propre mais marche)
2026-05-06 correction arrêt d'urgence cassé
    [task_strategy.cpp, tofs.cpp]
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2026-05-08 correction degré -> radian
    [tofs.cpp]
2026-05-08 correction inversement zones tofs
    [tofs.cpp]
2026-05-11 fonction reset coord et temps tirette debug différent, non testé
    [main.cpp, task_strategy.cpp]
2026-05-13 correction ihm du debug (inversion état du switch un peu partout)
    [actuators.h, main.cpp, task_strategy.cpp]
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2026-05-13 ajout contrôle de l'actionneur de fin de match
2026-05-13 oublier de le mettre dans le commit d'avant
2026-05-13 inversion du sens du switch debug pour le remettre bien
2026-05-13 actionneur de fin de match moins marrant mais plus réglementaire
2026-05-14 code plus ou moins ok pour réduire le patinage (non testé) et suivre plusieurs coordonnées à la suite (testé)
2026-05-14 évitement juste au centre pour éviter les faux positifs
2026-05-14 correction du pid en double
    [main.cpp]
2026-05-14 changement coordonnées en fonction de la couleur ok reset de coord du début normalement réglé mais pas sûr
    [main.cpp, task_strategy.cpp]
2026-05-14 bug reset coord corrigé ?
    [task_strategy.cpp]
2026-05-14 ajout de marge pour éviter de tourner autour de la coordonnées cible
2026-05-14 diminution de l'évitement d'obstacle pour pousser les caisses, actionneur de fin de match uniquement en non debug
2026-05-15 ajout d'un 3e point de coord pour pousser les caisses si besoin
2026-05-15 problème de timerde fin de match enfin réglé
2026-05-15 modif un peu bizarre de l'arrêt d'urgence selon le côté et les coordonnées, pour pousser les caisses
2026-05-16 suppression des modif de l'évitement d'obstacle pour pousser les caisses
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
